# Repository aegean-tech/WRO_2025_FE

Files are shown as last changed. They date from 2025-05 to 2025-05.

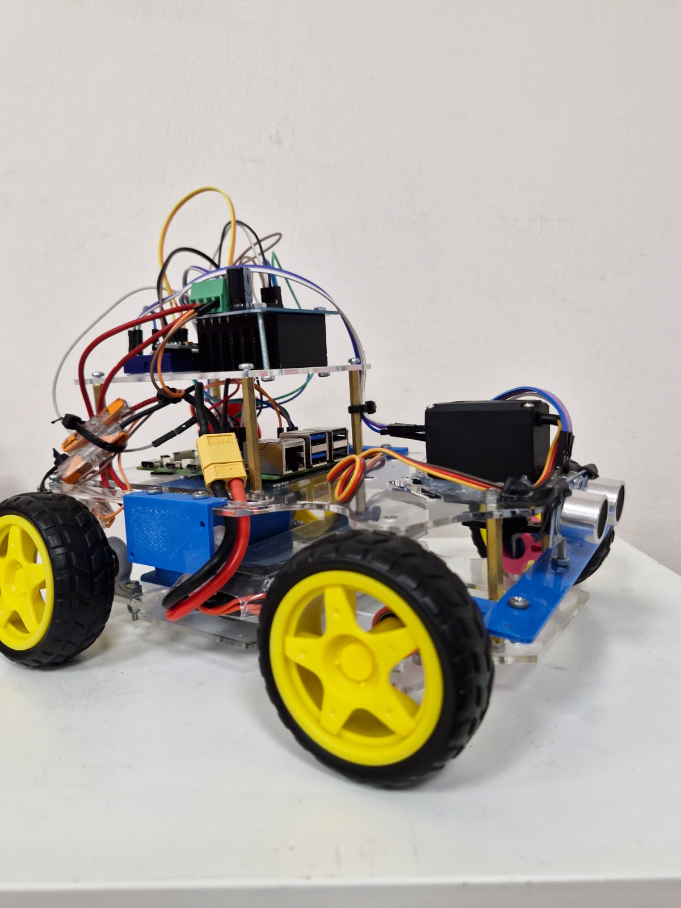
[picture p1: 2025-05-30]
vehicle-photos/IMG-20250530-WA0034.jpg

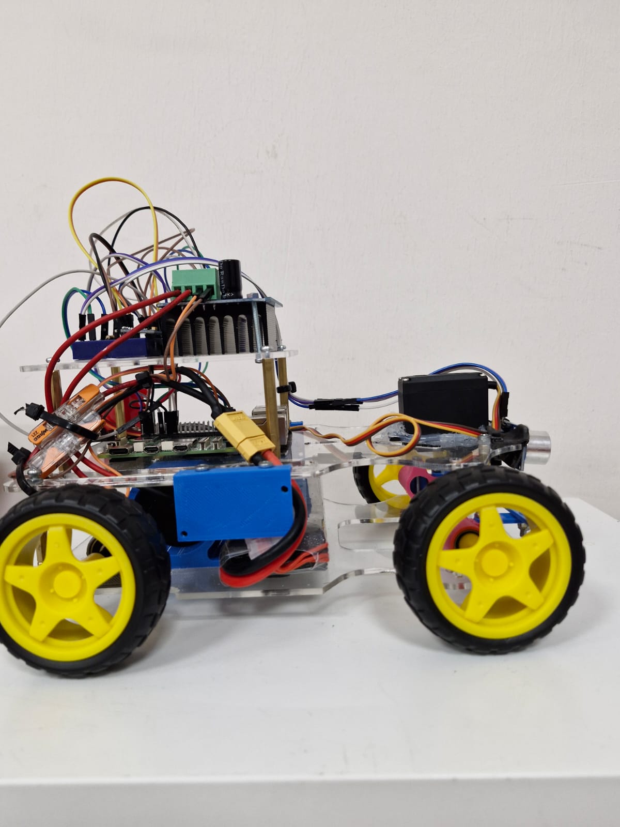
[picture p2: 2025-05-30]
vehicle-photos/IMG-20250530-WA0030.jpg

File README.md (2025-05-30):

# Mechanics 
Our robot has 3 floors that are independent from each other and each one has a 
unique functionality. These floors called “Lower Part”, “Middle Part” and “Upper Part”. 
For the floors we used plexi material. In this section we are going to illustrate these 
parts and their functionalities. The general of the robot length is 25 and our robots 
width is 18. Also our robot weighs 1320g and passes the rule.

## 1. Lower Part Of the Robot 
In the lower part of the chassis, we integrate the essential mechanical 
systems responsible for the robot’s movement, including the drive system, 
steering system, and the LiPo battery that powers the drive hub. This 
section is designed to provide structural stability while ensuring that the 
components responsible for motion are securely housed and properly aligned 
with the rest of the robot’s framework. 
Our drive system is built around two yellow rubber wheels, each with a 
diameter of 65mm and a weight of 38 grams. These wheels are 
carefully selected for their balance between traction and size, making them 
suitable for both speed and maneuverability on different surfaces. Both 
wheels are mounted onto a single shaft, allowing synchronized rotation, which 
is crucial for maintaining directional stability during forward or backward 
movement. 

The motor we use is a 12V, 35mm, 960 RPM DC Gearmotor, 
chosen for its balance of torque and speed. Its built-in gearbox allows us to 
harness high torque at a reasonable rotation speed, which is essential for 
moving the robot with both force and control, especially when carrying 
additional components on the upper floors. This motor is mounted securely to 
the chassis using a custom bracket to prevent vibration and misalignment, 
which could affect the gear connection and wheel performance. 

We use a Profuse LiPo battery to power our motor controller. It 
provides stable and sufficient energy for the drive system. An XT60 
connector is attached to ensure a secure and efficient power connection with 
minimal loss. 

## 2.  Middle Part Of the Robot 
In the middle part of the chassis, we house several critical electronic and 
control components that serve as the brain and sensory hub of the robot. This 
section includes the microcontroller, steering servo, main power switch, 
and ultrasonic sensors, all strategically placed for optimal performance and 
accessibility during maintenance or upgrades. 
At the heart of this layer lies the Raspberry Pi 5 with 8GB RAM, 
which functions as the robot’s main microcontroller. The Raspberry Pi is 
responsible for executing all high-level software operations, such as 
processing sensor inputs, controlling the movement systems, handling 
camera data, and managing the overall workflow of the robot. Its processing 
power and memory capacity make it suitable for running multiple scripts 
simultaneously and handling real-time operations efficiently. 

The steering servo, which controls the front wheels' angle, is also integrated 
into the middle part of the chassis. Although the actual turning mechanism is 
located on the lower part of the robot, the servo motor itself is mounted on the 
middle layer to save space and maintain structural integrity. To connect the 
servo to the steering system, we designed and 3D printed a custom shaft 
tunnel — a precisely aligned hole through the middle floor — which allows the 
servo shaft to reach down to the steering assembly on the lower level.
This design effectively transfers the servo’s motion while keeping the 
motor safely positioned and reducing stress on the structure. 
In addition to these, we included a physical switch in the middle floor to act 
as a main power control unit. This switch is wired directly between the LiPo 
battery and the motor controller, enabling us to safely start or shut down the 
robot without disconnecting any wires. This not only enhances safety during 
operation but also simplifies troubleshooting and testing during development 
phases. 

Another essential part of the middle section is the ultrasonic sensor system. 
We mounted three HC-SR04 ultrasonic sensors to allow the robot to 
perceive and interact with its environment. One sensor is placed facing 
forward to detect obstacles in the robot’s path, while the other two are 
positioned on the left and right sides to monitor lateral distances. These 
sensors are mounted securely using 3D-printed custom beds that are 
designed to fit the robot’s structure and keep the sensors stable and 
accurately aligned. These mounts also provide easy removal and 
replacement, making the system modular and upgrade-friendly. 
Together, the components on the middle floor form the core of the robot’s 
decision-making and navigation systems. Their layout was carefully planned 
to ensure compactness, accessibility, and efficient cable management all 
of which contribute to a robust and professional robotic platform.

## 3. Upper Part Of the Robot 
This part of the robot is smaller than the other floors of the robot. In this part 
we have the motor controller and our Raspberry Pi Module V3 
camera on the upper part of the robot.  
 
# Software 

We use Raspberry Pi OS for coding our components. Using a micro sd card for 
uploading a OS to Raspberry and connecting a micro HDMI cable to use its 
interface. Our software developes by two parts. First part we have robot 
functionalities and second part is to detect boxes using camera module. In our code 
each component has own file. Then we gathering all the useful methods and perform 
the continuous sequence in the main file. 

## 1. Robot Functionalities 
Our robot’s movement functionalities are implemented across three separate 
files, each dedicated to controlling a specific component of the robot. The first 
file manages the servo motor functionalities. In this file, the servo motor’s 
PWM port is configured, and its movements are controlled accordingly. A total 
of four functions are defined for the servo. The set_angle(angle) function 
allows precise adjustment of the servo to the desired angle. Additionally, three 
directional functions facilitate steering: steer_left() sets the servo to 60 
degrees to turn the robot left, steer_center() positions the servo at 90 degrees, 
representing the center or neutral position for straight movement, and 
steer_right() moves the servo to 120 degrees to turn right. These functions 
enable accurate and straightforward control of the robot’s steering based on 
the servo motor’s position. 

The second file handles the ultrasonic sensor code. This Python script utilizes 
the lgpio library to interface with ultrasonic distance sensors on a Raspberry 
Pi or similar Linux-based systems. It defines a class named UltrasonikSensor, 
which configures and operates each sensor by assigning specific GPIO pins 
for trigger (TRIG) and echo (ECHO) functions. The class’s olc method sends a 
short pulse from the TRIG pin and listens for its reflection on the ECHO pin, 
measuring the time delay to calculate the distance using the speed of sound. 
Three sensors are initialized to measure distances at the front, right, and left 
sides of the robot. The program continuously reads and displays these 
measurements every second, making it suitable for obstacle detection in 
robotic applications. It should be noted that there is a typographical error in 
the class constructor, where init is used instead of the correct __init__, which 
must be corrected for the class to function properly. 

The third file contains the drive motor control code. This code specifies the 
GPIO pins used for the right PWM (RPWM), left PWM (LPWM), left enable 
(L_EN), and right enable (R_EN) signals. Four primary functions are defined 
to control the robot’s movement: forward(), backward(), stop(), and cleanup(). 
The forward() function powers the motors at a speed value of 200 to move the 
robot forward, with appropriate HIGH and LOW signals to set the motor 
direction. The backward() function similarly sets the motors to move backward 
at the same speed. The stop() function halts the motors without requiring any 
speed parameters. Finally, the cleanup() function is invoked at the start and 
end of the program to properly reset the GPIO pins and prevent conflicts or 
resource leaks. 

Together, these three files provide coordinated control over the robot’s 
mobility and environmental awareness. The servo motors enable precise 
steering, ultrasonic sensors detect obstacles in the robot’s surroundings, and 
the drive motors facilitate safe and controlled movement. Ensuring the 
correctness and efficiency of these codes is critical for achieving reliable and 
effective robot performance. 

## 2. Detecting Boxes 
For detecting and sorting boxes, our robot relies on a color detection system, 
which enables it to identify boxes based on their distinct colors and respond 
accordingly. The system is implemented in two separate Python files: one 
dedicated to calibrating the colors of the boxes, and the other responsible for 
performing real-time sorting actions based on the live camera feed. 
The color detection process is divided into two main stages: calibration and 
real-time sorting. 

During calibration, we ensure that the environment is consistently lit to avoid 
discrepancies caused by lighting conditions. We place each box under the 
camera's view, making sure that shadows and reflections are minimized. The 
user then clicks on a specific region of the box within the camera frame, and 
the software captures the color data at that pixel. This data includes HSV 
(Hue, Saturation, Value) or RGB (Red, Green, Blue) values, which are 
essential for accurate color detection. 
These sampled color values are stored in a .json configuration file. This file 
acts as a reference for the real-time sorting script, allowing the robot to 
identify the boxes by comparing their detected colors with the calibrated 
values. This method ensures consistent and accurate detection, even across 
multiple sessions. 

Once calibration is completed, the real-time detection system becomes active. 
The camera continuously analyzes the incoming video feed to search for 
boxes that match the calibrated color profiles. When a box is detected, a 
bounding box is drawn around it for visual confirmation, and a small dot is 
marked at the center of the detected box for tracking purposes. 
To determine the appropriate movement, the screen is virtually divided into 
three equal vertical sections: left, center, and right. Depending on where the 
center dot of the detected box lies, the robot takes the necessary action to 
align itself with the box. 
For example, if a green box is detected and its center lies in the right section 
of the screen, the robot turns left until the box is aligned with the center or left 
section. Once the box reaches the target area, the robot stabilizes itself and 
continues forward, effectively completing the sorting process. 
This approach not only allows precise interaction with the environment but 
also gives us the flexibility to handle boxes of different colors and positions in 
real time. Thanks to the modular structure of the code, additional colors or 
actions can easily be integrated into the system in future versions. 

Prototyping Process and Improvements 
Throughout the development process, we went through several prototyping stages to 
arrive at a functional and efficient final robot design. One of the key components we 
focused on was the steering system. Initially, we experimented with placing the servo 
motor responsible for steering on the lowest floor of the robot. However, this led to 
an imbalance between the front and back wheels due to the height difference. To 
address this, we relocated the servo to the middle floor and used a custom 3D
printed structure to transfer the servo shaft down to the steering mechanism on the 
lower level. This approach not only resolved the height discrepancy but also resulted 
in a smooth and precise steering system that aligned well with competition 
standards. 

During this prototyping phase, we also considered using a downward-facing color 
sensor to detect floor colors, such as orange and blue, to guide the robot’s 
directional decisions. The idea was to let the robot decide whether to go left or right 
based on the color it detected underneath. While this method showed some initial 
promise, it was ultimately replaced by a more reliable and adaptable solution 
involving ultrasonic sensors. By placing sensors on both sides of the robot, we could 
compare the distance readings. If the right-side ultrasonic detected a significantly 
greater distance than the left-side sensor, it indicated that the robot had moved 
closer to the left and needed to correct by turning right. This method proved more 
consistent under varying lighting conditions and floor textures. 
For the drive system, we tested two major prototypes. In the first design, we 
attempted to directly couple the motor and wheel shafts without any gears. This 
approach introduced many mechanical challenges, including poor alignment and 
limited control over speed or torque. Despite multiple attempts and adjustments, we 
couldn't achieve a stable and effective connection. 

In the second design iteration, we decided to incorporate connecting gears between 
the motor and the wheel shaft. Initially, we planned to place the motor underneath 
the floor and align the gear system beneath the plexiglass. However, this setup 
faced a new challenge: the motor's vertical height did not fit within the space 
between the floors. To overcome this, we reoriented the motor horizontally and 
routed the gear system on top of the plexiglass surface. This adjustment allowed the 
wheel shaft to align perfectly with the front wheels in terms of height, maintaining 
structural symmetry. Moreover, the gear-based configuration granted us the flexibility 
to modify gear ratios, letting us fine-tune the system for either higher torque or 
increased speed based on the requirements of the match. 

One of the significant software improvements we implemented was the addition of a 
calibration mode for color detection. Initially, we faced challenges in reliably 
identifying the colors of boxes due to varying lighting conditions, which affected the 
camera's performance. To resolve this, we developed a dedicated calibration 
command. This command allows the robot to dynamically recalibrate its color 
thresholds before operation. As described in the Software section, this mode greatly 
increased the accuracy and consistency of our real-time color-based box detection 
and sorting system.

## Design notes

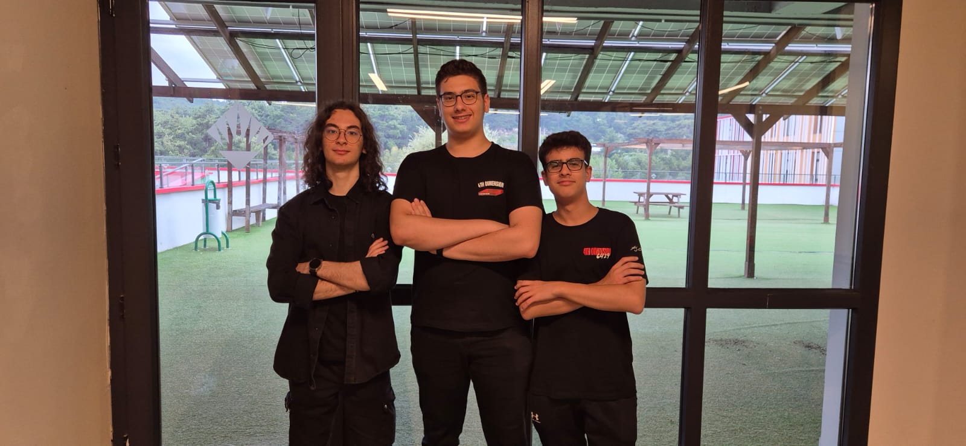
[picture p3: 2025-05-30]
team-photos/normal_photo.jpg

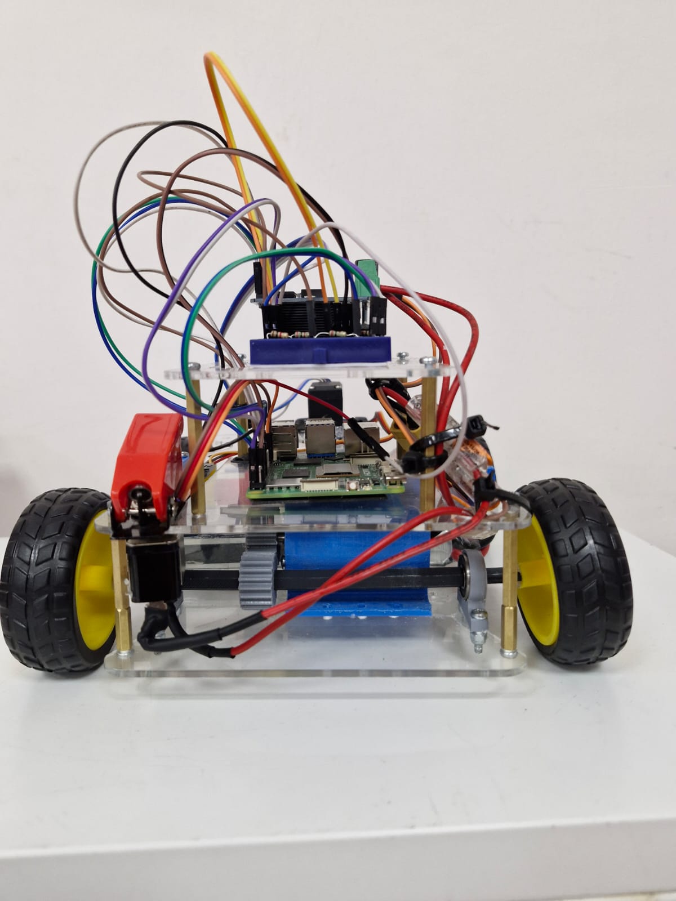
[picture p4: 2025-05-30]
vehicle-photos/IMG-20250530-WA0031.jpg

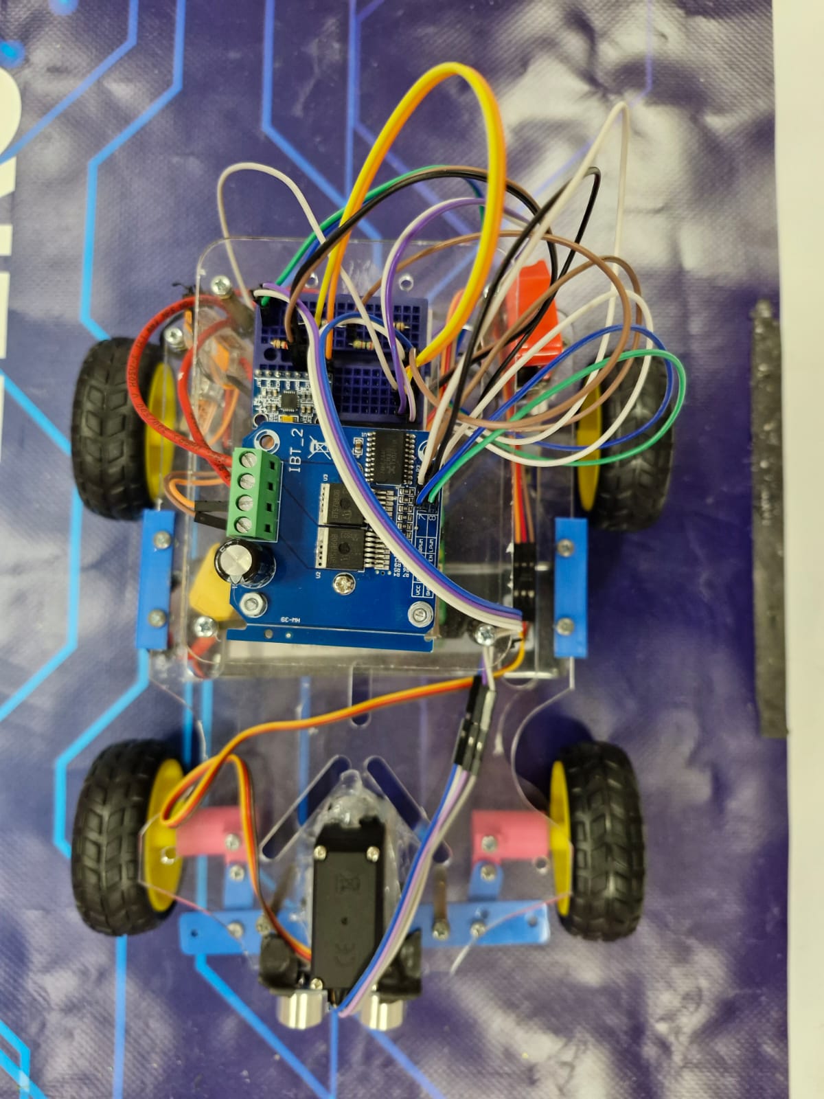
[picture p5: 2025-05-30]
vehicle-photos/IMG-20250530-WA0028.jpg

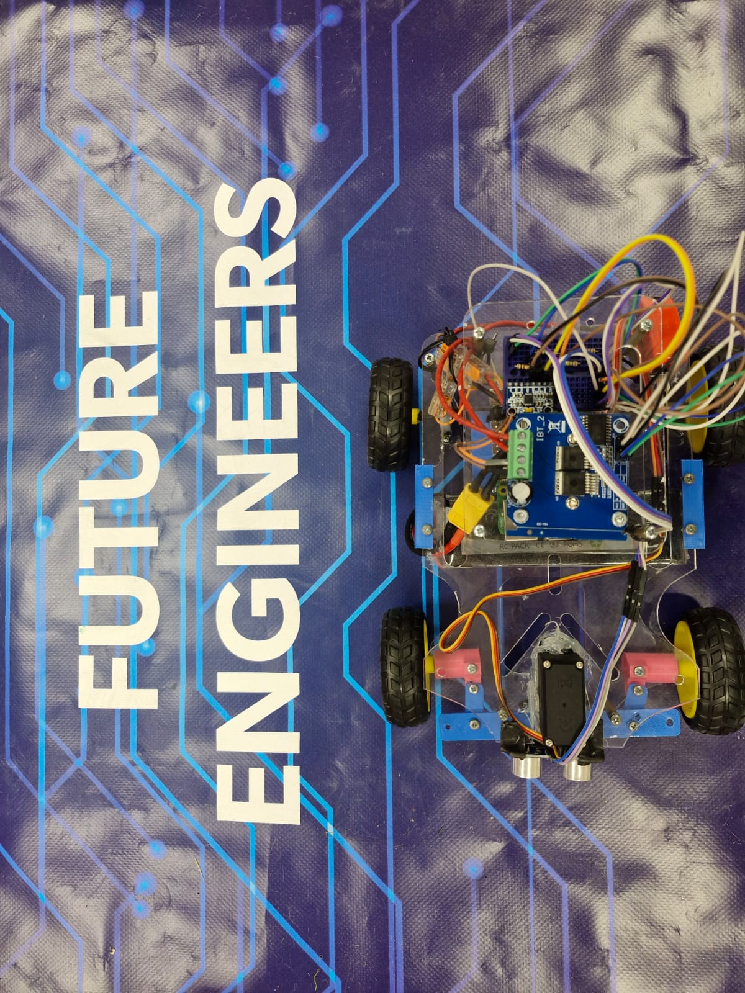
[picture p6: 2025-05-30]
vehicle-photos/IMG-20250530-WA0029.jpg

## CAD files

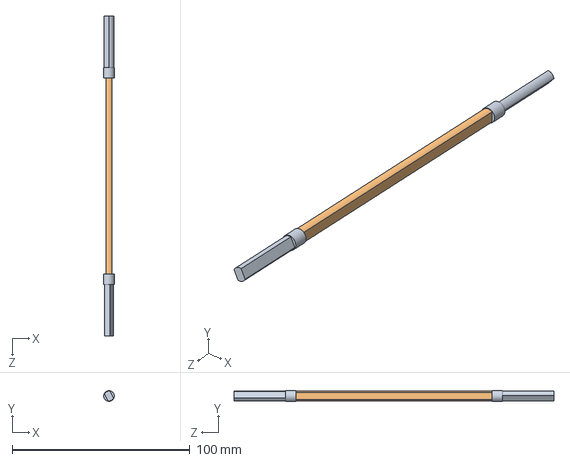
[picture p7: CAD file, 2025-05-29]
models/Assem1.SLDASM
6.00 x 6.00 x 180.0 mm
ana_şaft
rulman_girecek_parça x 2

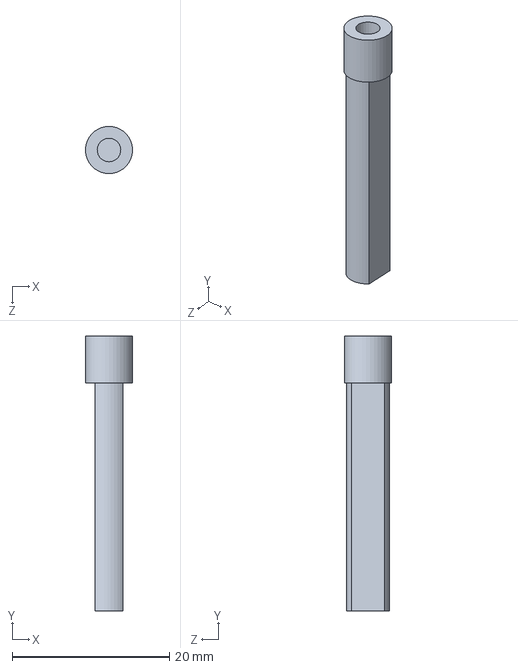
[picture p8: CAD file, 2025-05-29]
models/rulman_girecek_parça.SLDPRT
5.98 x 35.0 x 6.00 mm

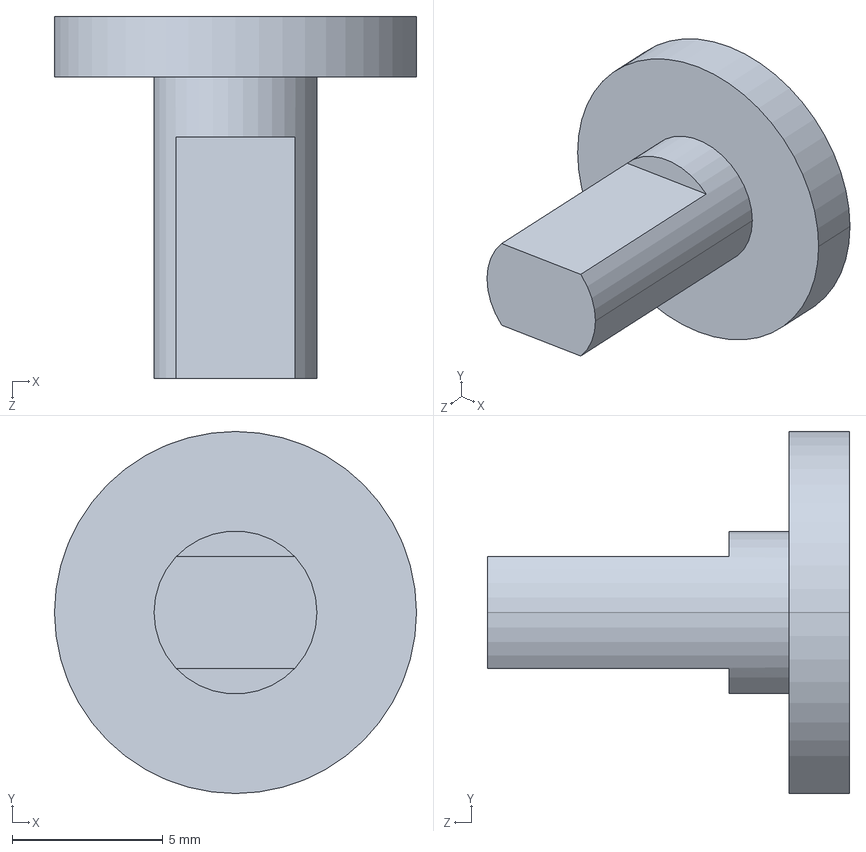
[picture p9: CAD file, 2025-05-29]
models/tekerlek_şaftı.SLDPRT
12.0 x 12.0 x 12.0 mm

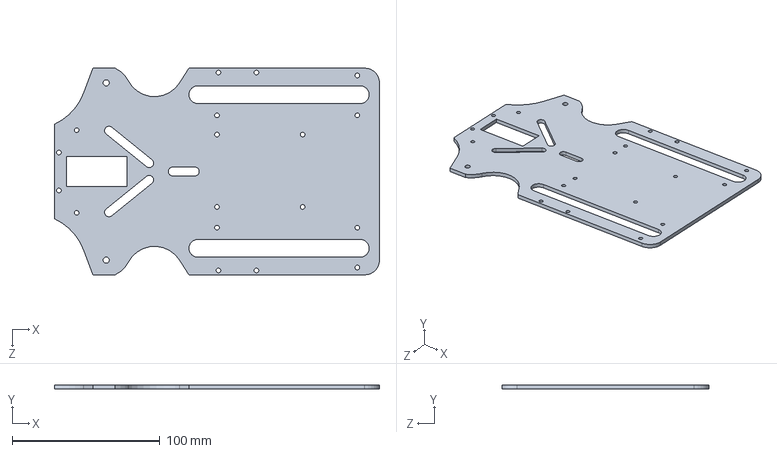
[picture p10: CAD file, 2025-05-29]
models/ust_govde.SLDPRT
220.0 x 3.00 x 140.0 mm

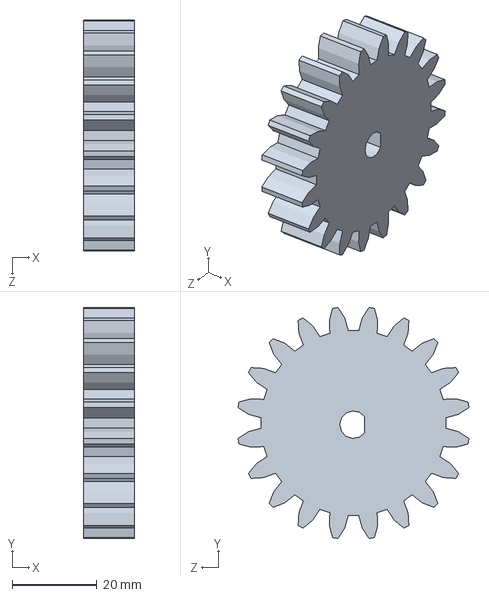
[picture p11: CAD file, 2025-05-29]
models/motorgearokulölçüleri.SLDPRT
12.0 x 54.5 x 54.5 mm

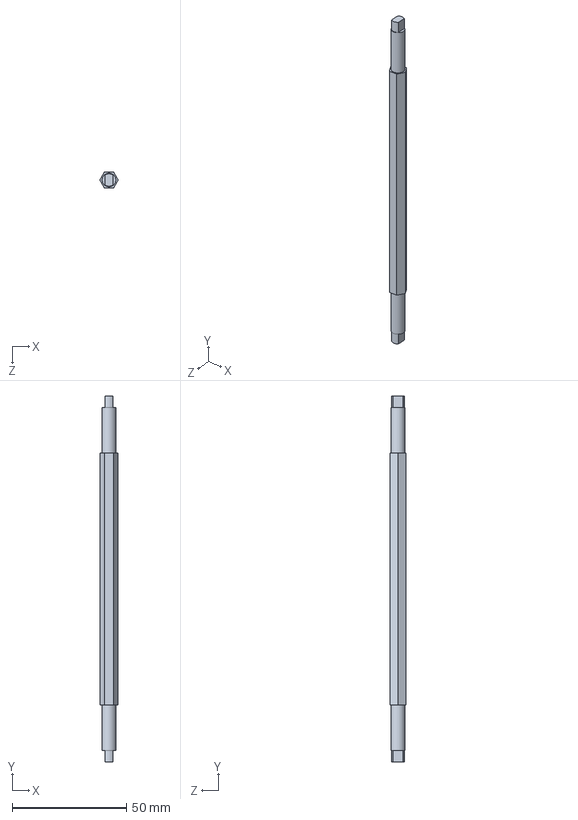
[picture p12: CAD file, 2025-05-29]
models/aks.SLDPRT
8.08 x 160.0 x 7.00 mm

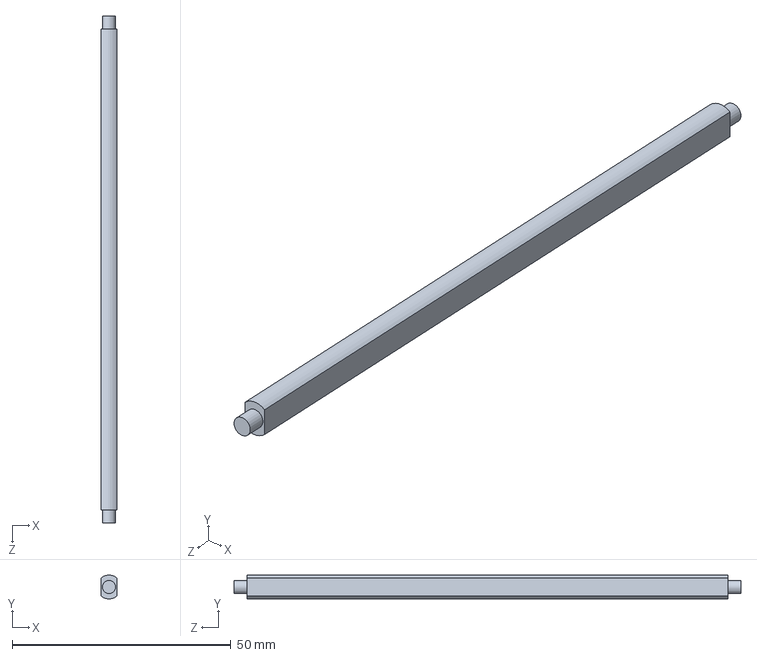
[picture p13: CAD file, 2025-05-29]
models/ana_şaft.SLDPRT
3.60 x 5.47 x 116.0 mm

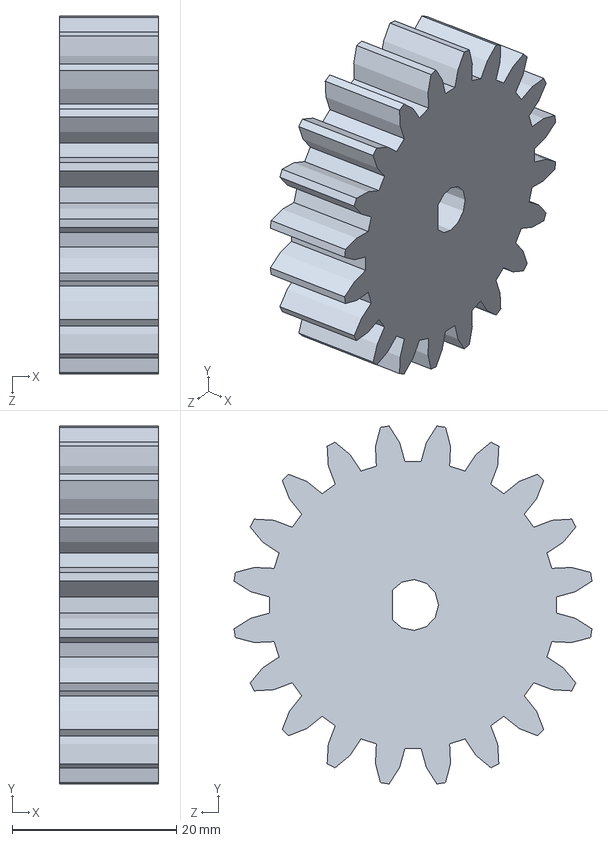
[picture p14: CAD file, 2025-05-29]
models/yeniaksgear.SLDPRT
12.0 x 43.6 x 43.6 mm

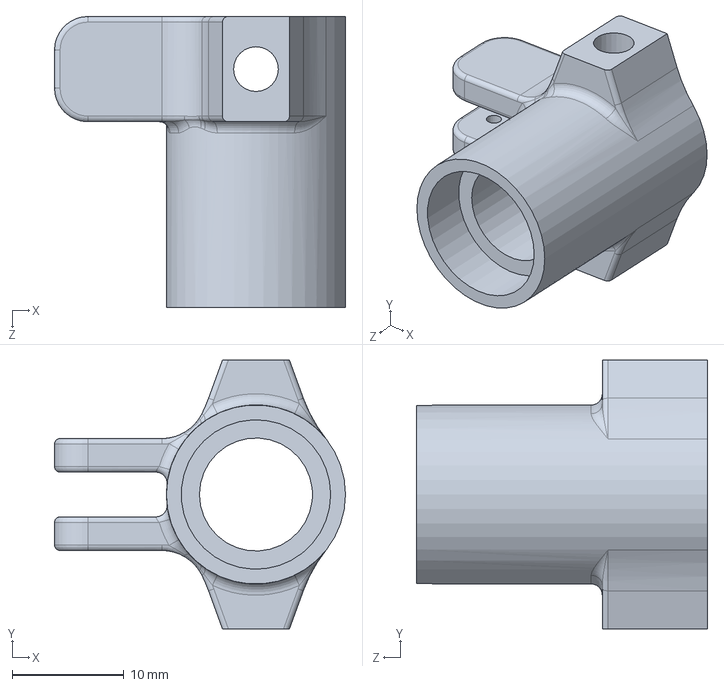
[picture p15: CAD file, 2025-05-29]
models/tekerleğegirenparça.SLDPRT
26.0 x 24.0 x 26.0 mm

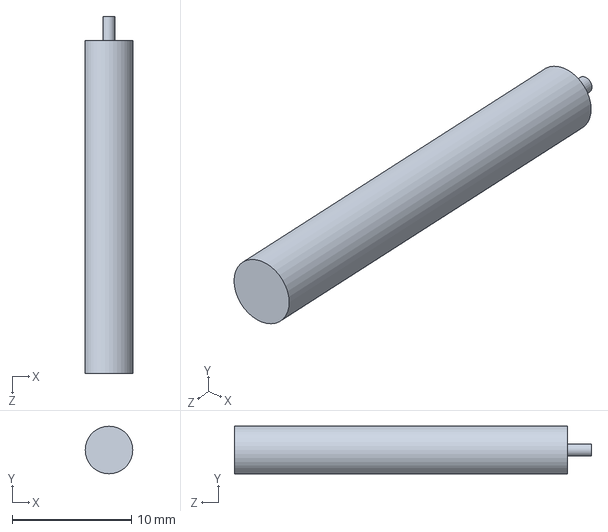
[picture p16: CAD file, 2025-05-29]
models/servoşaft.SLDPRT
4.00 x 4.00 x 30.0 mm

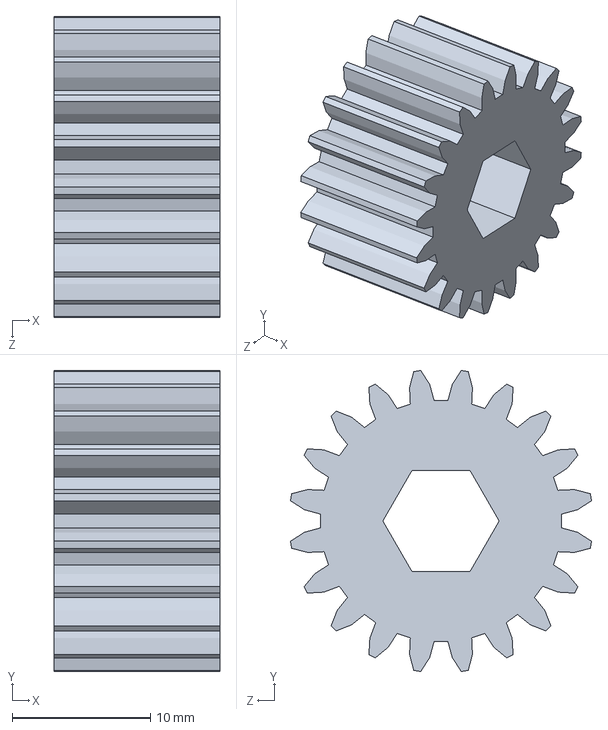
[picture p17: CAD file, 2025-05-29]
models/aksagirengear.SLDPRT
12.0 x 21.8 x 21.8 mm

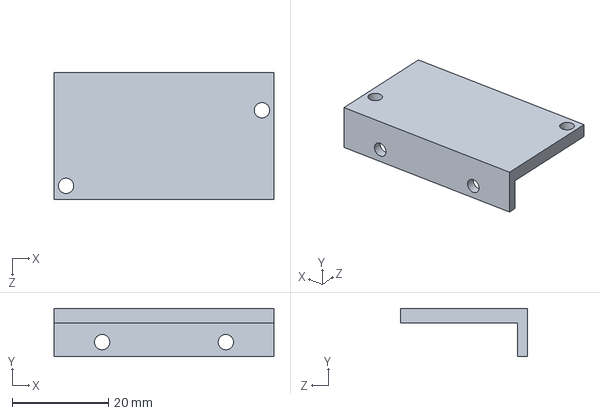
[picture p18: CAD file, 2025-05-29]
models/ultrasonik_tutucu.SLDPRT
45.7 x 10.0 x 26.3 mm

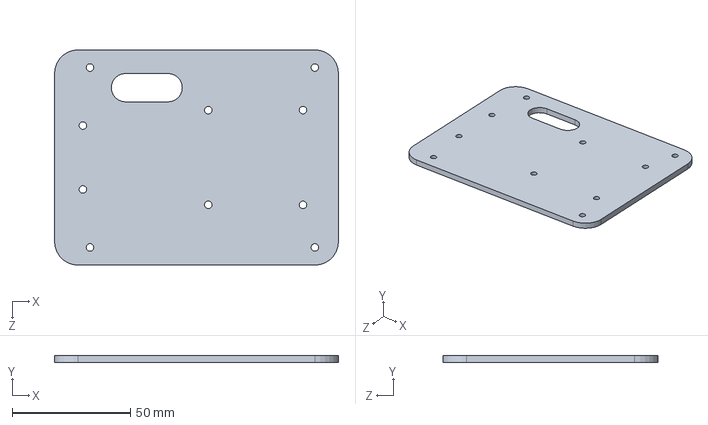
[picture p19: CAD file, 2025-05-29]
models/ust_plate.SLDPRT
120.0 x 3.00 x 91.0 mm

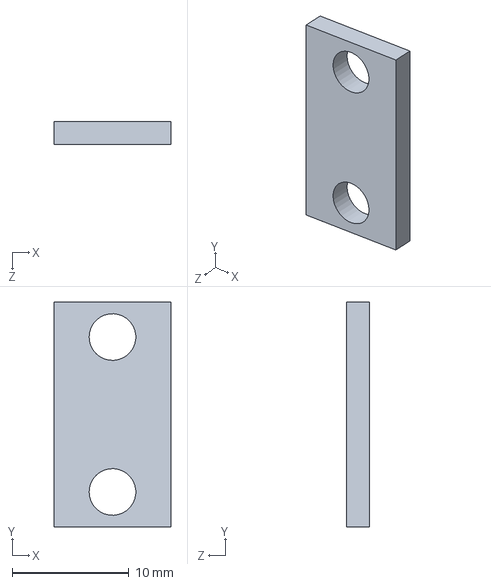
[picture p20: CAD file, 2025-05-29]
models/aralayıcı.SLDPRT
10.0 x 19.3 x 2.00 mm

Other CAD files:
models/ana_assembly.SLDASM
models/motorassembly.SLDASM
models/alt_govde.SLDPRT
models/45mm_standoff.SLDPRT
models/alt_govde.DXF
models/boru.SLDPRT
models/motor_tutma_safti.SLDPRT
models/motoragirengear.SLDPRT
models/motortutucu.SLDPRT
models/rulman.SLDPRT
models/rulman_yataklama.SLDPRT
models/spacer.SLDPRT

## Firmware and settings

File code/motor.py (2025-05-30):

import RPi.GPIO as GPIO
import time

class Motor:
    def __init__(self, l_en=27, r_en=18, rpwm=23, lpwm=22, pwm_frequency=100):
        # Set up GPIO mode and disable warnings
        GPIO.setmode(GPIO.BCM)
        GPIO.setwarnings(False)
        
        self.rpwm_pin = rpwm
        self.lpwm_pin = lpwm
        self.l_en_pin = l_en
        self.r_en_pin = r_en

        # Set all the pins as outputs
        GPIO.setup(self.rpwm_pin, GPIO.OUT)
        GPIO.setup(self.lpwm_pin, GPIO.OUT)
        GPIO.setup(self.l_en_pin, GPIO.OUT)
        GPIO.setup(self.r_en_pin, GPIO.OUT)

        # Enable both motor directions on the H-bridge
        GPIO.output(self.r_en_pin, True)
        GPIO.output(self.l_en_pin, True)

        # Initialize PWM on RPWM and LPWM pins with the specified frequency
        self.rpwm = GPIO.PWM(self.rpwm_pin, pwm_frequency)
        self.lpwm = GPIO.PWM(self.lpwm_pin, pwm_frequency)

        # Start PWM with 0 duty cycle
        self.rpwm.start(0)
        self.lpwm.start(0)

    def forward(self, speed=100):
        """İleri sürüş: right PWM = speed, left PWM = 0"""
        self.rpwm.ChangeDutyCycle(0)
        self.lpwm.ChangeDutyCycle(speed)

    def backward(self, speed=100):
        """Geri sürüş: left PWM = speed, right PWM = 0"""
        self.rpwm.ChangeDutyCycle(speed)
        self.lpwm.ChangeDutyCycle(0)

    def stop(self):
        """Motoru durdur"""
        self.rpwm.ChangeDutyCycle(0)
        self.lpwm.ChangeDutyCycle(0)

    def cleanup(self):
        """PWM’i durdur ve GPIO konfigürasyonunu temizle"""
        self.rpwm.stop()
        self.lpwm.stop()
        GPIO.cleanup()


def main():
    # Motor sürücüsü pinlerini varsayılan değerlerle başlat
    motor = Motor(l_en=27, r_en=18, rpwm=23, lpwm=22, pwm_frequency=100)
    motor.forward(100)
    try:
        print("Motor ileri")
        motor.forward(80)     # %80 hızla ileri
        time.sleep(3)         # 3 saniye bekle

        print("Motor durduruluyor")
        motor.stop()
        time.sleep(1)

        print("Motor geri")
        motor.backward(80)    # %80 hızla geri
        time.sleep(3)

        print("Motor durduruluyor")
        motor.stop()
        time.sleep(1)

    finally:
        print("GPIO temizleniyor")
        motor.cleanup()       # PWM ve GPIO’yu sıfırla

if __name__ == "__main__":
    main()

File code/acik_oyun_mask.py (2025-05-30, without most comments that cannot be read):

import cv2
import numpy as np
from picamera2 import Picamera2


# 1) Kalibrasyon Parametreleri


KNOWN_DISTANCE = 30.0
KNOWN_WIDTH    = 5.0
MEASURED_PIXEL_WIDTH = 200


FOCAL_LENGTH = (MEASURED_PIXEL_WIDTH * KNOWN_DISTANCE) / KNOWN_WIDTH





PINK_LOWER = np.array([140, 50, 50])
PINK_UPPER = np.array([170, 255, 255])


WHITE_LOWER = np.array([0,   0, 200])
WHITE_UPPER = np.array([180, 25, 255])




def distance_to_camera(pixel_width):
    """
    Piksel geni�li�inden (w) cm cinsinden uzakl�k d�ner.
    """
    return (KNOWN_WIDTH * FOCAL_LENGTH) / float(pixel_width)

def mask_colors(frame):
    """
    BGR frame � HSV � pembe & beyaz maskeleri olu�turur.
    Beyaz maskeye biraz morfolojik temizlik uygular.
    """
    hsv = cv2.cvtColor(frame, cv2.COLOR_BGR2HSV)
    mask_pink  = cv2.inRange(hsv, PINK_LOWER, PINK_UPPER)
    mask_white = cv2.inRange(hsv, WHITE_LOWER, WHITE_UPPER)
    # Beyaz maskeyi temizleyelim
    kernel = cv2.getStructuringElement(cv2.MORPH_ELLIPSE, (5,5))
    mask_white = cv2.morphologyEx(mask_white, cv2.MORPH_OPEN,  kernel, iterations=2)
    mask_white = cv2.morphologyEx(mask_white, cv2.MORPH_CLOSE, kernel, iterations=2)
    return mask_pink, mask_white




def main():
    servo = ServoController(SERVO_PIN)
    servo.center()


    motor = Motor()
    motor.stop()

    cam = Picamera2()
    config = cam.create_preview_configuration(main={"format":"BGR888","size":(640,480)})
    cam.configure(config)
    cam.start()

    try:
        while True:
            frame = cam.capture_array()
            mask = mask_white(frame)
            cx_frame, cy_frame = draw_crosshair(frame)

            contours, _ = cv2.findContours(mask, cv2.RETR_EXTERNAL, cv2.CHAIN_APPROX_SIMPLE)
            target = None
            for cnt in contours:
                if cv2.contourArea(cnt) < 500:
                    continue
                x,y,w,h = cv2.boundingRect(cnt)
                dist = distance_to_camera(w)
                if abs(dist - TARGET_DISTANCE) <= DISTANCE_TOLERANCE:
                    target = (x + w//2, y + h//2, dist)
                    break

            if target:
                tx, ty, td = target
                dx = tx - cx_frame

                # ? Servo ile yatay hizalama
                if dx > CENTER_THRESH_PX:
                    servo.step_right()
                elif dx < -CENTER_THRESH_PX:
                    servo.step_left()


                if td > TARGET_DISTANCE + DISTANCE_TOLERANCE:
                    motor.forward(speed=60)
                elif td < TARGET_DISTANCE - DISTANCE_TOLERANCE:
                    motor.backward(speed=40)
                else:
                    motor.stop()


                cv2.circle(frame, (tx, ty), 5, (0,255,0), -1)
                cv2.putText(frame, f"{td:.1f}cm", (tx+10, ty),
                            cv2.FONT_HERSHEY_SIMPLEX, 0.5, (0,255,0), 2)
            else:
                motor.stop()  # hedef yoksa dur

            cv2.imshow("Mask White", mask)
            cv2.imshow("Detection", frame)

            if cv2.waitKey(1) & 0xFF == ord('q'):
                break

    finally:
        cam.stop()
        servo.cleanup()
        motor.stop()
        GPIO.cleanup()

if __name__ == "__main__":
    main()
